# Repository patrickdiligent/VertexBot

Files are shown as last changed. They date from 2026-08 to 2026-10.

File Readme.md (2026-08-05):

# VertexBox Hardware

This is the hardware part of the little affordable robot, "VertexBot". This is a project in its early inception. Once the hardware is finalised, we will assemble a swarm of these little buggers (max 32 in a flock by design),  and test various things, and learn. The robots will have image processing and audio/DSP capabilities and will identify between themselves with the help of coloured lights.

The software components are located at this project: https://github.com/asekerci/chromavertex

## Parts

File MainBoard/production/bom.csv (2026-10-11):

Designator | Footprint | Quantity | Value | LCSC Part #
C1, C2, C4, C5 | 0603 | 4 | 100nf | C343025
D1, D3 | 0805 | 2 | LED | C264416
Q1, Q2, Q3 | SOT-23 | 3 | BSS138
R1 | 0603 | 1 | 20K 0.1%
R10 | 0603 | 1 | 100k | C15458
R11, R12 | 0603 | 2 | 4.7K | C2784998
R13 | 0603 | 1 | 10K 0.1% | C413738
R14, R20 | 0603 | 2 | 1K | C2774267
R17, R19 | 2512 | 2 | 0.22 | C49655446
R2, R3, R4, R5, R6, R7 | 0603 | 6 | 10K | C15401
TP1, TP2, TP3, TP4, TP5, TP6 | TestPoint_Pad_3.0x3.0mm | 6 | TestPoint_Flag
U2, U4 | DGQ10_2P18X1P72 | 2 | DRV8830DGQR | C127591
U7, U8 | TO-92Flat | 2 | DRV5033AJxLPG | C201608

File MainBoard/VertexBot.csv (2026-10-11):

Reference | Qty | Value | DNP | Exclude from BOM | Exclude from Board | Footprint | Datasheet | Shop | LCSC Part # | Price
C1,C2 | 2 | 100nf |  |  |  | Capacitor_SMD:C_0603_1608Metric_Pad1.08x0.95mm_HandSolder | ~ |  | C343025
C4,C5 | 2 | 100nF |  |  |  | Capacitor_SMD:C_0603_1608Metric_Pad1.08x0.95mm_HandSolder | ~ |  | C343025
D1,D3 | 2 | LED |  |  |  | LED_SMD:LED_0805_2012Metric_Pad1.15x1.40mm_HandSolder | ~ |  | C264416
F1 | 1 | 0031.8211.G |  | Excluded from BOM |  | Vertex_Bot:FUSE_0031.8211_SCH | 0031.8211.G | digikey.com.au (ref 0031.8201.G) |  | $2.53
H1,H2,H3,H4,H5,H6,H7,H8,H9,H10,H11,H12,H13,H14,H15,H16,H17,H18 | 18 | MountingHole |  | Excluded from BOM |  | MountingHole:MountingHole_3.5mm_Pad | ~
J2 | 1 | I2C Extension |  | Excluded from BOM |  | Connector_PinHeader_2.54mm:PinHeader_1x04_P2.54mm_Vertical | ~ |  |  | $0.48
J3 | 1 | Left Motor |  | Excluded from BOM |  | Connector_JST:JST_PH_S2B-PH-K_1x02_P2.00mm_Horizontal | ~ | digikey.com.au |  | $1.17
J4 | 1 | 694106301002 |  | Excluded from BOM |  | Connector_THT_Wurth:J_Wurth_WR-DC_694106301002 | https://www.we-online.com/catalog/datasheet/694106301002.pdf?ki | digikey.com.au (ref 694106301002) |  | $1.41
J5 | 1 | Right Motor |  | Excluded from BOM |  | Connector_JST:JST_PH_S2B-PH-K_1x02_P2.00mm_Horizontal | ~ | digikey.com.au (ref S2B-PH-K-S) |  | $1.17
J6 | 1 | Led Strip |  | Excluded from BOM |  | Connector_JST:JST_PH_B3B-PH-K_1x03_P2.00mm_Vertical | ~ | digikey.com.au (ref B3B-PH-K-S) |  | $0.23
Q1,Q2,Q3 | 3 | BSS138 |  |  |  | Package_TO_SOT_SMD:SOT-23 | https://www.onsemi.com/pub/Collateral/BSS138-D.PDF
R1 | 1 | 20K 0.1% |  |  |  | Resistor_SMD:R_0603_1608Metric_Pad0.98x0.95mm_HandSolder | ~
R2,R3,R4,R5,R6,R7 | 6 | 10K |  |  |  | Resistor_SMD:R_0603_1608Metric_Pad0.98x0.95mm_HandSolder |  |  | C15401
R10 | 1 | 100k |  |  |  | Resistor_SMD:R_0603_1608Metric_Pad0.98x0.95mm_HandSolder |  |  | C15458
R11,R12 | 2 | 4.7K |  |  |  | Resistor_SMD:R_0603_1608Metric_Pad0.98x0.95mm_HandSolder |  |  | C2784998
R13 | 1 | 10K 0.1% |  |  |  | Resistor_SMD:R_0603_1608Metric_Pad0.98x0.95mm_HandSolder |  |  | C413738
R14,R20 | 2 | 1K |  |  |  | Resistor_SMD:R_0603_1608Metric_Pad0.98x0.95mm_HandSolder |  |  | C2774267
R17,R19 | 2 | 0.22 |  |  |  | Resistor_SMD:R_2512_6332Metric_Pad1.40x3.35mm_HandSolder |  |  | C49655446
SW1 | 1 | SW_SPST |  | Excluded from BOM |  | Vertex_Bot:L101011MS02Q | https://www.digikey.com/en/products/detail/c-k/L101011MS02Q/484142 | L101011MS02Q (ref L101011MS02Q) |  | $6.13
TP1,TP2,TP3,TP4,TP5,TP6 | 6 | TestPoint_Flag |  |  |  | TestPoint:TestPoint_Pad_3.0x3.0mm | ~
U2,U4 | 2 | DRV8830DGQR |  |  |  | Vertex_Bot:DGQ10_2P18X1P72 | https://www.ti.com/lit/gpn/drv8830 |  | C127591
U3 | 1 | S13V30F5 |  | Excluded from BOM |  | Vertex_Bot:S13V30F5_HORIZONTAL | ~ | Core Electronics |  | $30
U5 | 1 | INMP441 |  | Excluded from BOM |  | Vertex_Bot:INMP441 |  | https://www.aliexpress.com/item/1005013251461379.html |  | $3
U6 | 1 | 0.96 INCH OLED |  | Excluded from BOM |  | Vertex_Bot:OLED_0_96_INCH |  | :https://www.aliexpress.com/item/1005006901360788.html (SSD1315) |  | $3.85
U7,U8 | 2 | DRV5033AJxLPG |  |  |  | Package_TO_SOT_THT:TO-92Flat | https://www.ti.com/lit/ds/symlink/drv5033.pdf |  | C201608
U9 | 1 | MPU 6050 |  | Excluded from BOM |  | Vertex_Bot:MPU6050 |  | https://www.aliexpress.com/item/1005008714169630.html |  | $4.29
U10 | 1 | MAX4466 (LEFT) |  | Excluded from BOM |  | Vertex_Bot:MAX4466_HORIZONTAL |  | (3 pins) https://www.aliexpress.com/item/1005012568399288.html |  | $1.99
U11 | 1 | MAX4466 (RIGHT) |  | Excluded from BOM |  | Vertex_Bot:MAX4466_HORIZONTAL |  | (3 pins) https://www.aliexpress.com/item/1005012568399288.html |  | $1.99
U12 | 1 | ESP32-S3-CAM-B |  | Excluded from BOM |  | Vertex_Bot:CAM_B_BOARD_VERTICAL | ~ | (PCBWAY) |  | $2.05 (5 for $11)
U13 | 1 | ESP32-S3-CAM-A |  | Excluded from BOM |  | Vertex_Bot:CAM_A_BOARD_VERTICAL | ~ | (PCBWAY) |  | $2.05
U14 | 1 | MAX98357A |  | Excluded from BOM |  | Vertex_Bot:MAX98357 | https://www.analog.com/media/en/technical-documentation/data-sheets/MAX98357A-MAX98357B.pdf | https://www.aliexpress.com/item/1005006096022361.html |  | $3.04

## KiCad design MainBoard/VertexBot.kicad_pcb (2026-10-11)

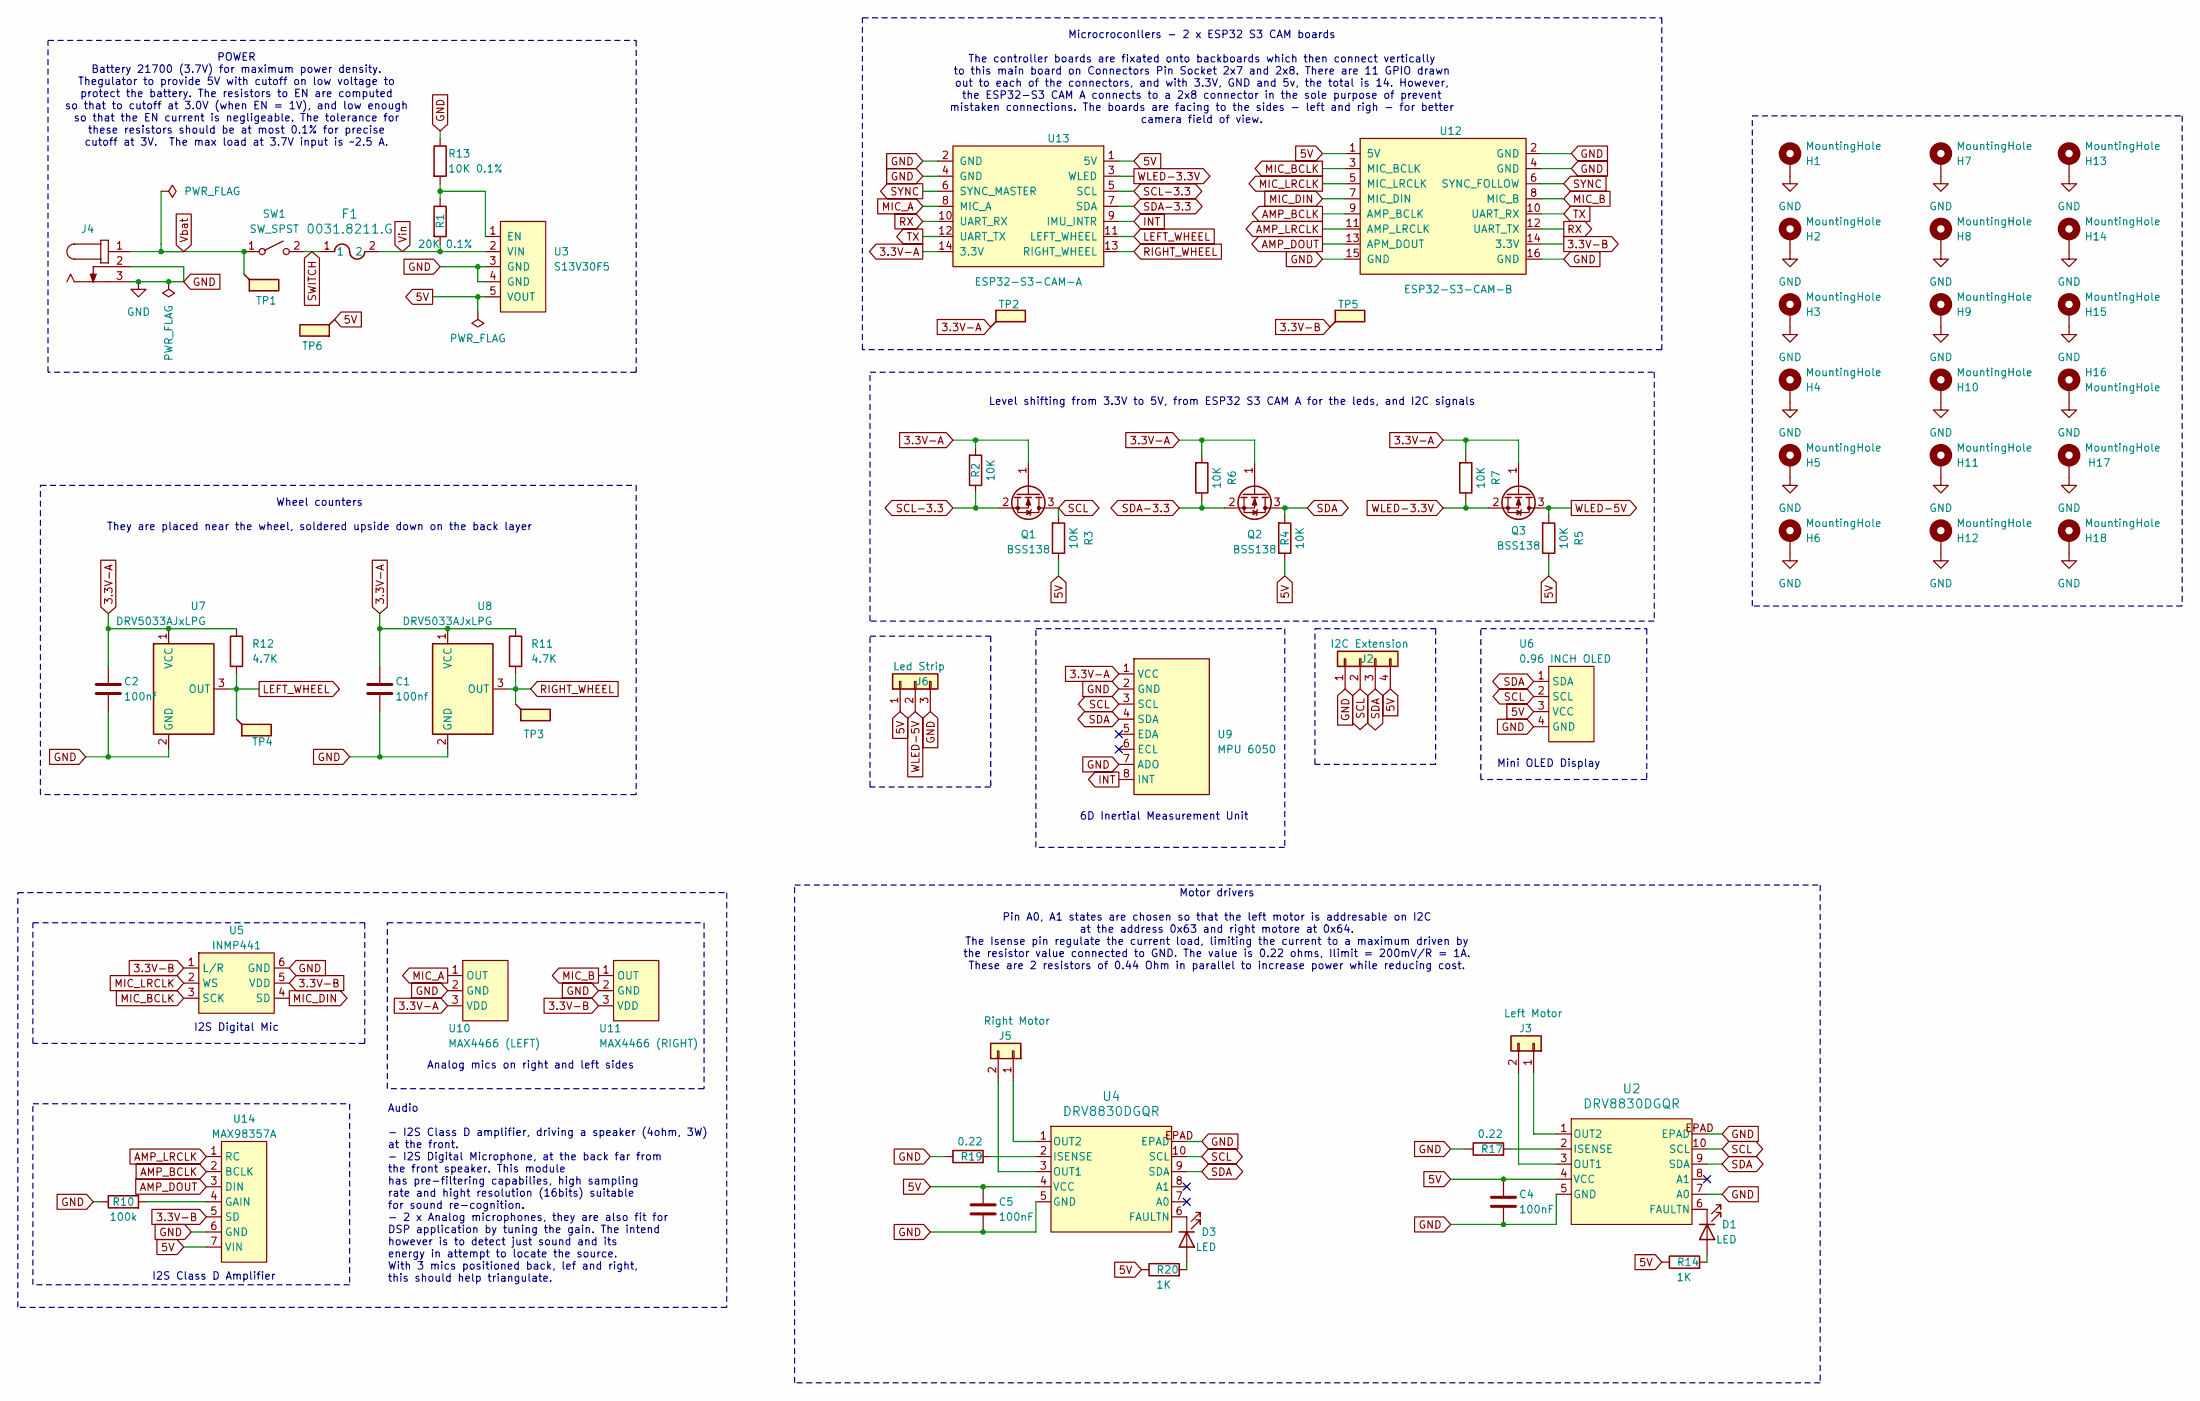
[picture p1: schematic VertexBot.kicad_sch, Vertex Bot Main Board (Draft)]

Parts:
C1, C2: 100nf; C_0603_1608Metric_Pad1.08x0.95mm_HandSolder; LCSC Part # C343025
C4, C5: 100nF; C_0603_1608Metric_Pad1.08x0.95mm_HandSolder; LCSC Part # C343025
D1, D3: LED; LED_0805_2012Metric_Pad1.15x1.40mm_HandSolder; LCSC Part # C264416
F1: 0031.8211.G; FUSE_0031.8211_SCH
H1, H2, H3, H4, H5, H6, H7, H8, H9, H10, H11, H12, H13, H14, H15, H16, H17, H18: MountingHole; MountingHole_3.5mm_Pad
J2: I2C Extension; PinHeader_1x04_P2.54mm_Vertical
J3: Left Motor; JST_PH_S2B-PH-K_1x02_P2.00mm_Horizontal
J4: 694106301002; J_Wurth_WR-DC_694106301002; Working Voltage (V (DC)) 30; Part Number 694106301002
J5: Right Motor; JST_PH_S2B-PH-K_1x02_P2.00mm_Horizontal
J6: Led Strip; JST_PH_B3B-PH-K_1x03_P2.00mm_Vertical
Q1, Q2, Q3: BSS138; SOT-23
R1: 20K 0.1%; R_0603_1608Metric_Pad0.98x0.95mm_HandSolder
R2, R3, R4, R5, R6, R7: 10K; R_0603_1608Metric_Pad0.98x0.95mm_HandSolder; LCSC Part # C15401
R10: 100k; R_0603_1608Metric_Pad0.98x0.95mm_HandSolder; LCSC Part # C15458
R11, R12: 4.7K; R_0603_1608Metric_Pad0.98x0.95mm_HandSolder; LCSC Part # C2784998
R13: 10K 0.1%; R_0603_1608Metric_Pad0.98x0.95mm_HandSolder; LCSC Part # C413738
R14, R20: 1K; R_0603_1608Metric_Pad0.98x0.95mm_HandSolder; LCSC Part # C2774267
R17, R19: 0.22; R_2512_6332Metric_Pad1.40x3.35mm_HandSolder; LCSC Part # C49655446
SW1: SW_SPST; L101011MS02Q
TP1, TP2, TP3, TP4, TP5, TP6: TestPoint_Flag; TestPoint_Pad_3.0x3.0mm
U2, U4: DRV8830DGQR; DGQ10_2P18X1P72; LCSC Part # C127591
U3: S13V30F5; S13V30F5_HORIZONTAL
U5: INMP441
U6: 0.96 INCH OLED; OLED_0_96_INCH
U7, U8: DRV5033AJxLPG; TO-92Flat; LCSC Part # C201608
U9: MPU 6050; MPU6050
U10: MAX4466 (LEFT); MAX4466_HORIZONTAL
U11: MAX4466 (RIGHT); MAX4466_HORIZONTAL
U12: ESP32-S3-CAM-B; CAM_B_BOARD_VERTICAL
U13: ESP32-S3-CAM-A; CAM_A_BOARD_VERTICAL
U14: MAX98357A; MAX98357

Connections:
3.3V-A: C1.1, C2.1, Q1.1 (G), Q2.1 (G), Q3.1 (G), R2.2, R6.2, R7.2, R11.1, R12.1, TP2.1, U7.1 (VCC), U8.1 (VCC), U9.1 (VCC), U10.3 (VDD), U13.14 (3.3V)
3.3V-B: TP5.1, U5.1 (L/R), U5.5 (VDD), U11.3 (VDD), U12.14 (3.3V), U14.5 (SD)
5V: C4.1, C5.1, J2.4, J6.1, R3.1, R4.1, R5.1, R14.1, R20.1, TP6.1, U2.4 (VCC), U3.5 (VOUT), U4.4 (VCC), U6.3 (VCC), U12.1 (5V), U13.1 (5V), U14.7 (VIN)
AMP_BCLK: U12.9 (AMP_BCLK), U14.2 (BCLK)
AMP_DOUT: U12.13 (APM_DOUT), U14.3 (DIN)
AMP_LRCLK: U12.11 (AMP_LRCLK), U14.1 (RC)
GND: C1.2, C2.2, C4.2, C5.2, H1.1, H2.1, H3.1, H4.1, H5.1, H6.1, H7.1, H8.1, H9.1, H10.1, H11.1, H12.1, H13.1, H14.1, H15.1, H16.1, H17.1, H18.1, J2.1, J4.2, J4.3, J6.3, R10.1, R13.1, R17.1, R19.1, U2.5 (GND), U2.7 (A0), U2.EPAD, U2.V, U3.3 (GND), U3.4 (GND), U4.5 (GND), U4.EPAD, U4.V, U5.6 (GND), U6.4 (GND), U7.2 (GND), U8.2 (GND), U9.2 (GND), U9.7 (ADO), U10.2 (GND), U11.2 (GND), U12.2 (GND), U12.4 (GND), U12.15 (GND), U12.16 (GND), U13.2 (GND), U13.4 (GND), U14.6 (GND)
INT: U9.8 (INT), U13.9 (IMU_INTR)
LEFT_WHEEL: R12.2, TP4.1, U7.3 (OUT), U13.11 (LEFT_WHEEL)
MIC_A: U10.1 (OUT), U13.8 (MIC_A)
MIC_B: U11.1 (OUT), U12.8 (MIC_B)
MIC_BCLK: U5.3 (SCK), U12.3 (MIC_BCLK)
MIC_DIN: U5.4 (SD), U12.7 (MIC_DIN)
MIC_LRCLK: U5.2 (WS), U12.5 (MIC_LRCLK)
unnamed: D1.2 (A), R14.2
unnamed: D1.1 (K), U2.6 (FAULTN)
unnamed: D3.2 (A), R20.2
unnamed: D3.1 (K), U4.6 (FAULTN)
unnamed: J3.1, U2.1 (OUT2)
unnamed: J3.2, U2.3 (OUT1)
unnamed: J5.1, U4.1 (OUT2)
unnamed: J5.2, U4.3 (OUT1)
unnamed: R17.2, U2.2 (ISENSE)
unnamed: R1.1, R13.2, U3.1 (EN)
unnamed: R19.2, U4.2 (ISENSE)
unnamed: R10.2, U14.4 (GAIN)
RIGHT_WHEEL: R11.2, TP3.1, U8.3 (OUT), U13.13 (RIGHT_WHEEL)
RX: U12.12 (UART_TX), U13.10 (UART_RX)
SCL: J2.2, Q1.3 (D), R3.2, U2.10 (SCL), U4.10 (SCL), U6.2 (SCL), U9.3 (SCL)
SCL-3.3: Q1.2 (S), R2.1, U13.5 (SCL)
SDA: J2.3, Q2.3 (D), R4.2, U2.9 (SDA), U4.9 (SDA), U6.1 (SDA), U9.4 (SDA)
SDA-3.3: Q2.2 (S), R6.1, U13.7 (SDA)
SWITCH: F1.1, SW1.2 (B)
SYNC: U12.6 (SYNC_FOLLOW), U13.6 (SYNC_MASTER)
TX: U12.10 (UART_RX), U13.12 (UART_TX)
Vbat: J4.1, SW1.1 (A), TP1.1
Vin: F1.2, R1.2, U3.2 (VIN)
WLED-3.3V: Q3.2 (S), R7.1, U13.3 (WLED)
WLED-5V: J6.2, Q3.3 (D), R5.2

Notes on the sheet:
Wheel counters They are placed near the wheel, soldered upside down on the back layer
Audio - I2S Class D amplifier, driving a speaker (4ohm, 3W) at the front. - I2S Digital Microphone, at the back far from the front speaker. This module has pre-filtering capabilies, high sampling rate and hight resolution (16bits) suitable for sound re-cognition. - 2 x Analog microphones, they are 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
Analog mics on right and left sides
POWER Battery 21700 (3.7V) for maximum power density. Thegulator to provide 5V with cutoff on low voltage to protect the battery. The resistors to EN are computed so that to cutoff at 3.0V (when EN = 1V), and low enough so that the EN current is negligeable. The tolerance for these resistors should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
Level shifting from 3.3V to 5V, from ESP32 S3 CAM A for the leds, and I2C signals
I2S Class D Amplifier
Microcroconllers - 2 x ESP32 S3 CAM boards The controller boards are fixated onto backboards which then connect vertically to this main board on Connectors Pin Socket 2x7 and 2x8. There are 11 GPIO drawn out to each of the connectors, and with 3.3V, GND and 5v, the total is 14. However, the ESP32-S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
Motor drivers Pin A0, A1 states are chosen so that the left motor is addresable on I2C at the address 0x63 and right motore at 0x64. The Isense pin regulate the current load, limiting the current to a maximum driven by the resistor value connected to GND. The value is 0.22 ohms, Ilimit = 200mV/R = 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
Mini OLED Display
I2S Digital Mic
6D Inertial Measurement Unit

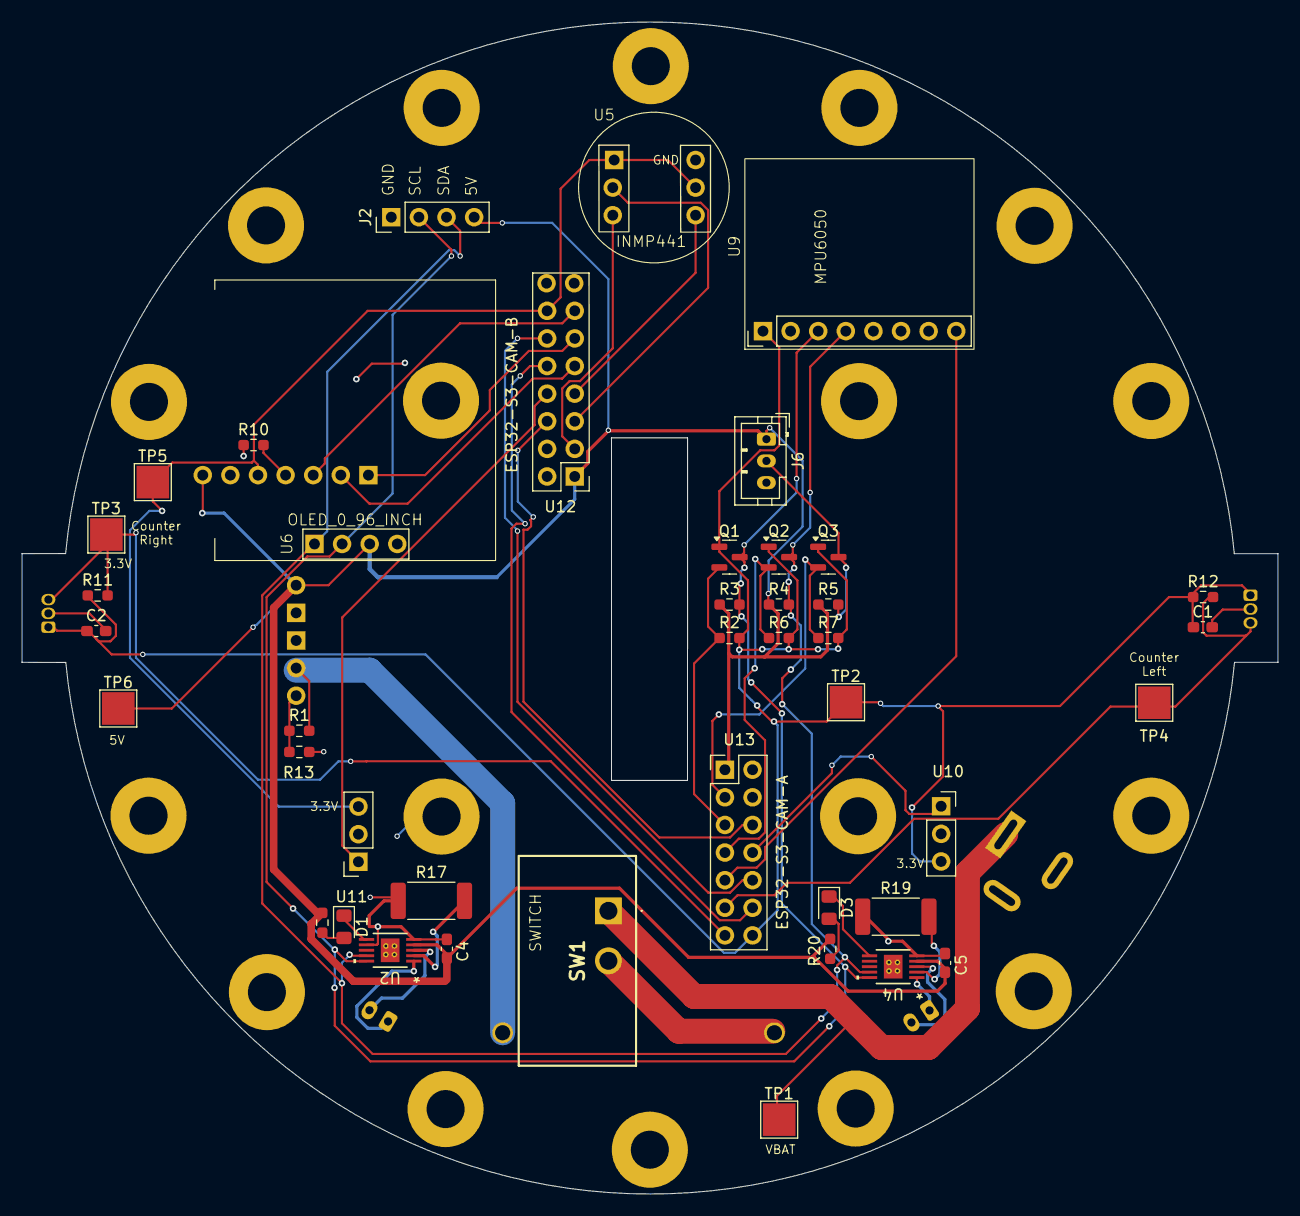
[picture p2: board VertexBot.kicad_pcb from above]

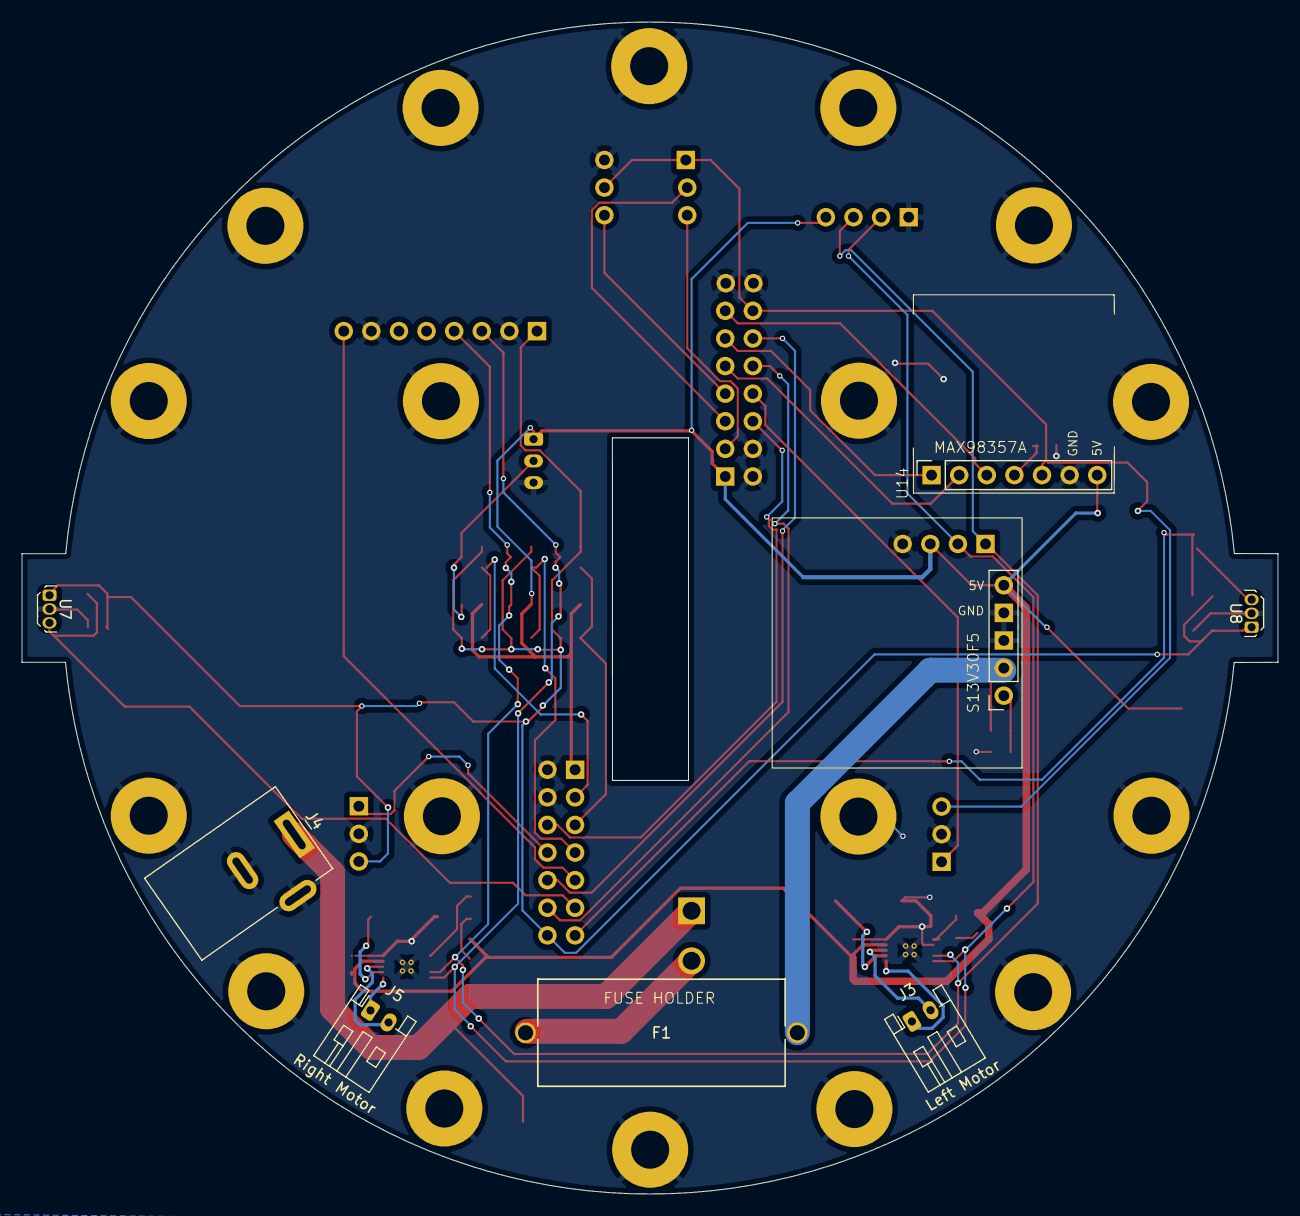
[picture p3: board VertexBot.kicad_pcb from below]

Board: 2 copper layers, 115.6 x 107.8 mm, 68 parts (8 on the bottom side), 39 nets.

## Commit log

2026-08-05 Initial files
    [CAM_A.kicad_pcb, CAM_A.kicad_sch, CAM_B.kicad_pcb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]
2026-08-05 Re-structure library (symbol and footprints)
2026-08-05 Add footprints for SMD passive components Link to public software repository
    [VertexBot.kicad_sch]
2026-08-05 Add INMP441 module footprint
    [VertexBot.kicad_sch]
2026-08-05 Footprint for OLED, INMP441, Test Points Fix Library broken dependency
    [VertexBot.kicad_sch]
2026-08-07 Library cleanup
    [VertexBot.kicad_sch]
2026-08-07 Add MAX98357 and S13V30F5 footprints
    [VertexBot.kicad_sch]
2026-08-10 Footprints complete and rough test placement on the board
    [VertexBot.kicad_sch]
2026-08-10 Fix for correct battery connector footprint
    [VertexBot.kicad_pcb, VertexBot.kicad_sch]
2026-08-12 Adjust divider values for cutoff at 3V (en = 1V) Add Tolerance (0.1%)
    [VertexBot.kicad_pcb, VertexBot.kicad_sch]
2026-08-12 Remove junction (accidently added by tool) and adjust colors
    [VertexBot.kicad_sch]
2026-08-22 - Relayed schematic with better modular approach (Global labels usage) - Edge cut so that now backboards are facing to the sides, central rectangular hole rotated by 90 - Some fooprints DRC'ed and fi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
    [MountingHoles.kicad_sch, VertexBot.kicad_pcb, VertexBot.kicad_sch]
2026-08-22 - Relayed main schematic
    [VertexBot.kicad_sch]
2026-08-22 Assign colors to power nets
2026-08-24 Adjust DRV8830DGQR to allow thermal pad connect to GND Adjust some of the modules courtyard Fix mounting holes symbols to have connection
    [MountingHoles.kicad_sch, VertexBot.kicad_pcb, VertexBot.kicad_sch]
2026-09-01 Completed Main PCB first draft (v0.1)
    [VertexBot.kicad_pcb, VertexBot.kicad_sch]
2026-09-18 Reviewed power requirements, adjusted power track widths Changed to DC barel connector with proper current rating Added corresponding symbol, footprint and 3D model
    [VertexBot.kicad_pcb, VertexBot.kicad_sch]
2026-09-26 Add 3D models for MPU3050, MAX98357, OLED Review MAX footprint placements to keep away from booster
    [VertexBot.kicad_pcb]
2026-09-26 Move MAX4466 (analog mics) away from USP connectors All 3D models update Add silkscreen user labels
    [VertexBot.kicad_pcb, VertexBot.kicad_sch]
2026-09-26 Minor fix
    [VertexBot.kicad_pcb]
2026-10-03 Added 3D model for the backboards and ESP32 S3 CAM
    [CAM_B.kicad_pcb, VertexBot.kicad_pcb]
2026-10-10 All project library paths relative to project folder
    [VertexBot.kicad_sch]
2026-10-11 JLCPCB parts, refs, shops Corrected missing pins for backboard B
    [VertexBot.csv, VertexBot.kicad_pcb, VertexBot.kicad_sch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]
